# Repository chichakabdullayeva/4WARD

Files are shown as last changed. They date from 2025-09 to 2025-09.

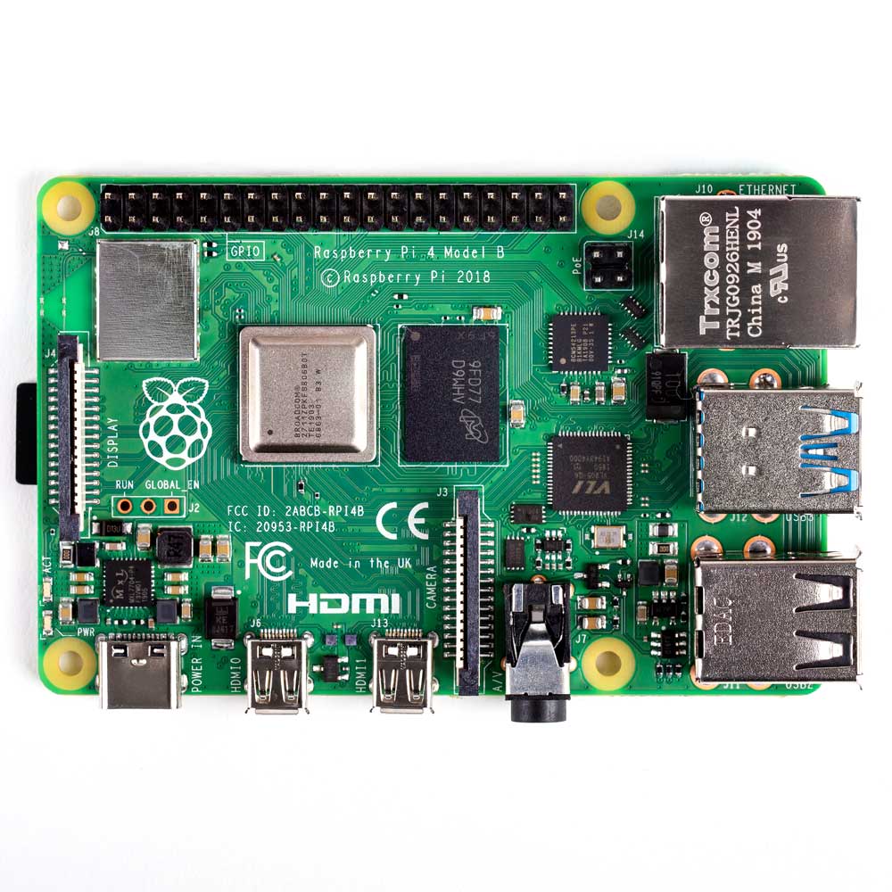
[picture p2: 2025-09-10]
components_picture/Raspberry PI Model 4B.jpg

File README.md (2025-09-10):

# 4Ward

# Engineering Materials for WRO Future Engineers 2025

This repository contains the engineering documentation for **self-driving vehicle of 4ward**, designed for the **World Robot Olympiad (WRO) Future Engineers 2025** competition.  
Our project showcases a fully autonomous vehicle capable of navigating challenges through innovative **mobility, power management, sensing, and obstacle management strategies**.

---

## Team Introduction

**Team 4Ward** consists of three members:  
- **Hakim Musazada**  
- **Shamil Mammadov**  
- **Chichak Abdullayeva**

We are students from **Baku Engineering University**, passionate about electronics, robotics, AI and autonomous systems.  
Our goal is to design a robust vehicle that balances **performance, reliability, and creativity**, inspired by real-world self-driving technology.

Team photos will be uploaded in the [`t-photos/`](./t-photos/) directory:  
- `team-official.jpeg`  → Formal team photo  
- `team-fun.jpeg` → Fun team photo  

---

## Vehicle Design Overview

Our vehicle is designed to excel in the WRO Future Engineers challenges, with a focus on **autonomous navigation, obstacle avoidance, and efficient power usage**.

### Mobility
- Drive system powered by a **single 6V 150 RPM DC motor**
- Rear-wheel drive via **gear system**.  
- **Surpass Hobby 9g D1090FE Digital Servo Motor** controls the front wheels for steering.  
- Motor driver: **TB6612FNG**, interfaced with **Raspberry Pi 4 Model B**.  

This configuration allows **sharp turns, stable movement, and smooth acceleration**.

---

### Power Management
- Powered by **two 3.7V 18650 Li-ion batteries** in series → ~**7.4V / 2200mAh**.  
- **Step-down voltage regulator** provides 5V for Raspberry Pi 4 Model B and sensors.  
- Includes **Battery Management System (BMS)** to prevent over-discharge.  
- Optimized for **20 minutes of continuous operation**.  

Challenge: Voltage drops under heavy motor load → **solved with capacitors** for stable supply.  

---

### Sensing
Our vehicle employs multiple sensors for navigation and obstacle detection:

- **HC-SR04 Ultrasonic Sensors (x3)** → front, left, right (range: 2m).  
- **TCS3200 Color Sensor (x1)** → detect track markers.  
- **Raspberry Pi Camera Module V1.3** → visual recognition & object detection.  

Data is processed in real time on **Raspberry Pi 4 Model B** with noise reduction via **moving average filter**.

---

### Obstacle Management
- Vehicle pauses when obstacle detected.  
- Scans with ultrasonic sensors → calculates alternative path using **rule-based algorithm**.  
- Dynamic obstacles:  
  - **Green cube → pass left**  
  - **Red cube → pass right**  

This ensures **reliable navigation** in the WRO environment.  
Sensor noise was reduced by **averaging multiple readings**.

---

## Electromechanical Schematics
Schematics will be uploaded in the [`schemes/`](./schemes/) directory:  

- `robot_schema_.png` and `robot_schema.jpg` → connections between Raspberry Pi 4 Model B, Camera, HC-SR04, TCS3200, Servo, TB6612FNG, Voltage Regulator, DC Motor and Battery.  

---

## Code Structure and Integration
Source code is located in the [`src/`](./src/) directory, written in **Python** for Raspberry Pi 4 Model B.  

### Code Modules
- `main.py` → Runs the core control loop, combining camera-based color detection, ultrasonic obstacle avoidance, servo steering, and motor control. 
- `camera&servo.py` → Processes camera feed to detect red/green signs and steers the servo using a PD controller.
- `color_sensor.py` → Reads RGB frequencies from TCS3200 sensor, normalizes values, and detects orange or blue objects. 
- `ultrasonic_test`  → Measures distance using HC-SR04 ultrasonic sensor with timeout handling to detect obstacles.
- `ultrasonic&servo&driver.py` → Integrates ultrasonic sensors, camera color detection, motor control, and servo steering for obstacle avoidance and navigation.
### Relation to Hardware
`ultrasonic_test.py` → GPIO 21 (TRIG Front), GPIO 20 (ECHO Front), GPIO 27 (TRIG Left), GPIO 17 (ECHO Left), GPIO 4 (TRIG Right), GPIO 23 (ECHO Right).

`camera_servo.py`' → GPIO 18 (servo pin for camera rotation).

`ultrasonic_servo_driver.py` → GPIO 18 (servo), GPIO 21/20 (front sensor), GPIO 27/17 (left sensor), GPIO 4/23 (right sensor), GPIO 13 (motor PWM), GPIO 24 (MOTOR_IN1), GPIO 25 (MOTOR_IN2).

`color_sensor.py` → Uses OpenCV with camera input (no GPIO pins).

`main.py` → Coordinates modules (no direct GPIO assignment).

## Component Photos
Located in [`components_picture/`](./components-picture/).  

- Raspberry Pi 4 Model B (4GB)  
- Motor (6V, 150 RPM)  
- TB6612FNG Motor Driver  
- HC-SR04 Ultrasonic Sensor  
- Raspberry Pi Camera Module  
- Servo Motor  
- TCS3200 Color Sensor
- LiPo Batteries 18650 

---

## Photos and Videos
- Vehicle Photos → [`v-photos/`](./v-photos/)  
  - `vehicle-front.jpg`, `vehicle-back.jpg`, `vehicle-left.jpg`, `vehicle-right.jpg`, `vehicle-top.jpg`, `vehicle-bottom.jpg`  
- Team Photos → [`t-photos/`](./t-photos/)  
- Demo Videos → [`video/READMDE.md`](./video/video.md) (links to YouTube, ≥30s per challenge)  

---

## Additional Resources
- [`models/`](./models/) → STL files for 3D-printed chassis parts

---

## Contact
For questions, contact us at:  
**team4ward.contact@gmail.com**

---

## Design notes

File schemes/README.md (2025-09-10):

# Note on the Color Sensor – WRO Future Engineers 2025

## Why the Color Sensor Is Missing in the Schematic
The wiring schematic for our vehicle was created using **Fritzing**.  
However, Fritzing does not currently provide a built-in component for the **TCS3200 Color Sensor** (or any similar color sensor).  
Because of this limitation, we were unable to include the color sensor in the uploaded schematic, even though it is an essential part of our actual hardware design.

---

## Purpose of the Color Sensor in Our Vehicle
Although it is missing from the schematic, the **color sensor is fully integrated** in our physical robot and serves a crucial function:

### **Primary Function: Lap Counting**
The main purpose of the color sensor is to **count how many laps the robot has completed** on the track.  
This is critical because:

1. **Race Strategy Requirement**  
   - According to the competition rules, the robot must **complete exactly 3 laps**  
   - After the 3rd lap, the robot must **automatically park** in the designated area

2. **How It Works**  
   - The sensor detects **specific color markers** placed on the track surface  
   - Each time the robot passes over 4 markers, it counts one lap  
   - After detecting the **third marker**, the robot activates its parking system

3. **Precision Timing**  
   - Accurate lap counting ensures the robot stops at the **exact required position**  
   - Without this sensor, the robot would not know when to begin parking procedures

---

## Conclusion
Even though the color sensor is not visible in the schematic due to software limitations, it is a **critical component** for lap counting in our robot.  
It provides the essential capability to:  
- Detect lap completion markers on the track  
- Count exactly 3 laps as required by competition rules  
- Trigger the parking system at the precise moment  

Thus, the **color sensor plays a vital role** in ensuring that our vehicle performs the complete race sequence correctly and stops after exactly 3 laps in the **WRO Future Engineers 2025** competition.

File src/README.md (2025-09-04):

# Source Code Instructions

## Run
python3 main.py

## Hardware
Servo → GPIO 18
Ultrasonic sensors:
  Front → TRIG=21, ECHO=20
  Left  → TRIG=27, ECHO=17
  Right → TRIG=4,  ECHO=23

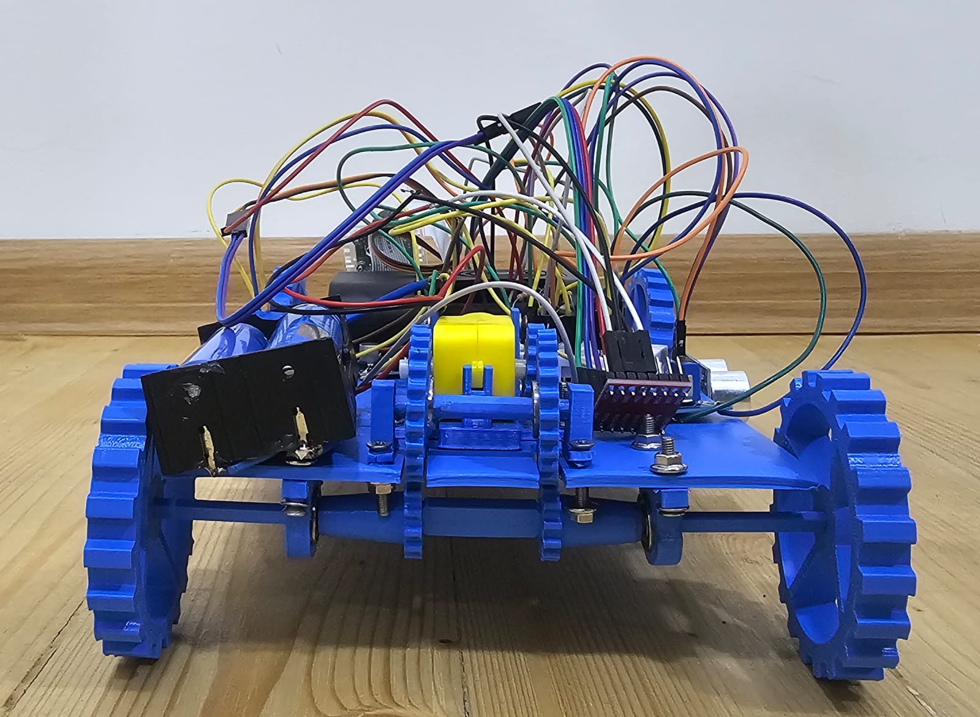
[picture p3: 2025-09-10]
v-photos/vehicle-back.jpg

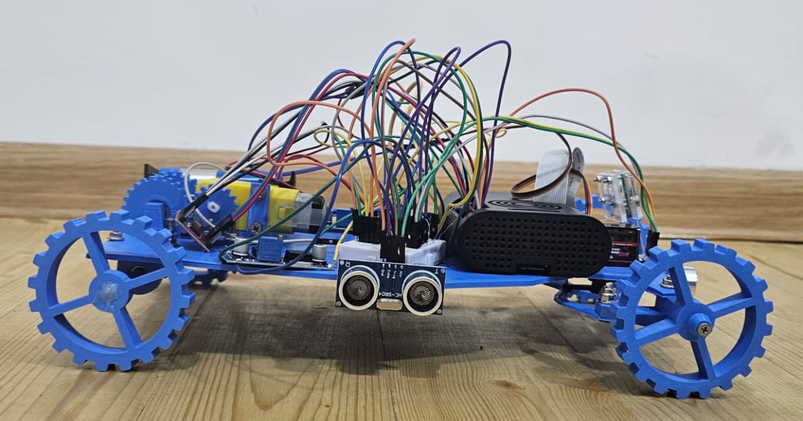
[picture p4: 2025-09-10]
v-photos/vehicle-right.jpg

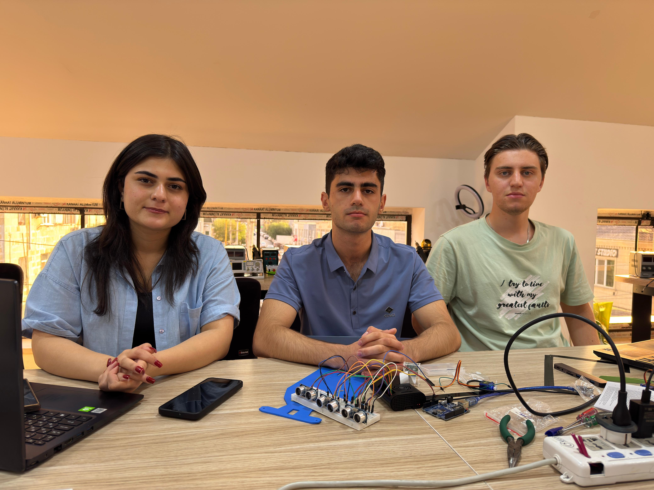
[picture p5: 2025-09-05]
t-photos/team-official.jpeg

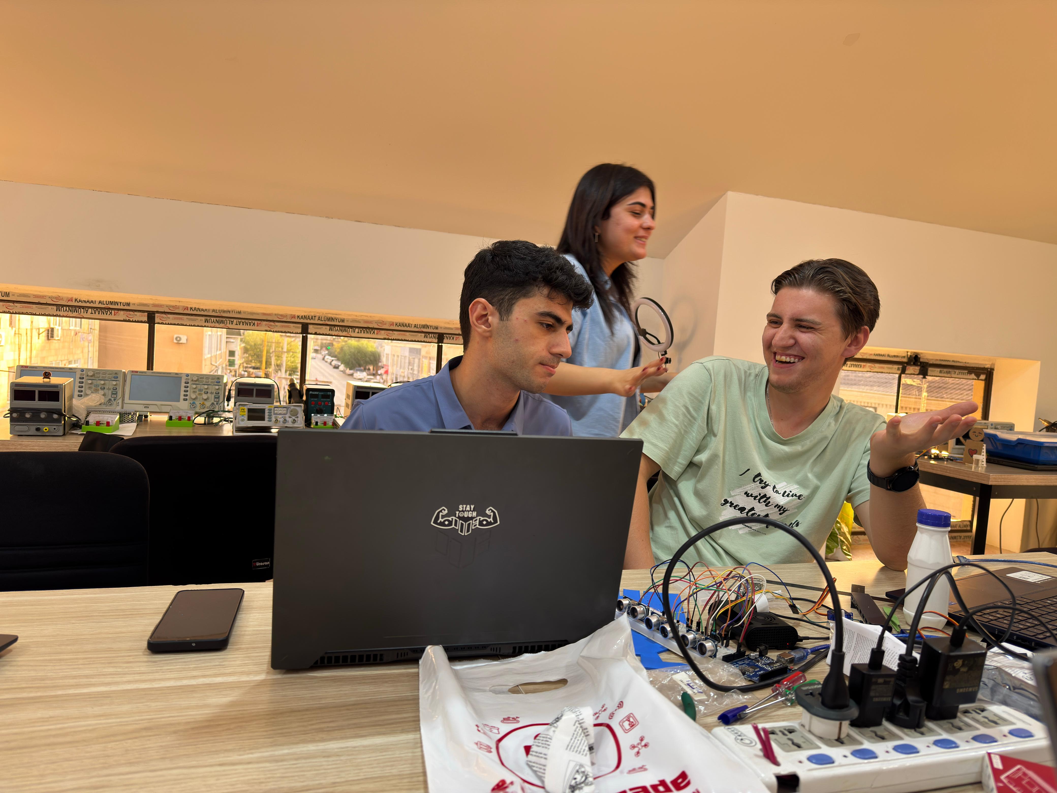
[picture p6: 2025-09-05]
t-photos/team-funny.jpeg

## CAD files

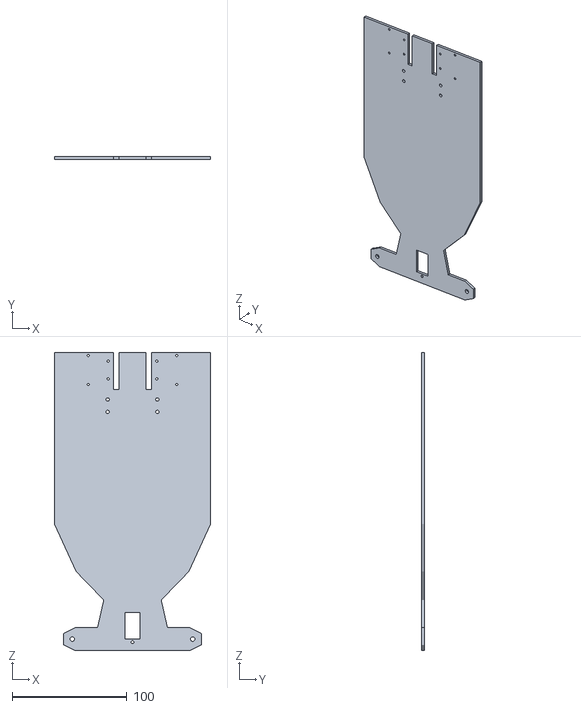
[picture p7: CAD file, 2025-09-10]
models/Part2.STL
136.2 x 2.50 x 260.0

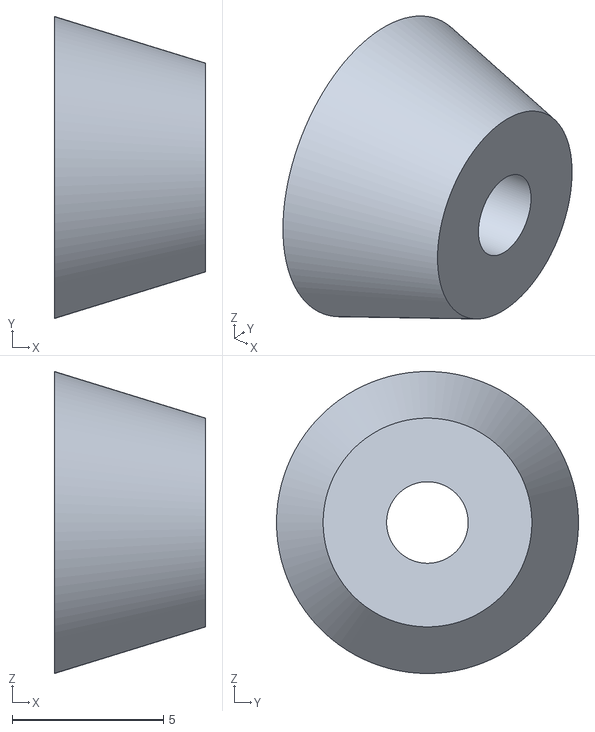
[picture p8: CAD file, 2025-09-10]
models/hubcap_rear.stl
5.00 x 10.0 x 10.0

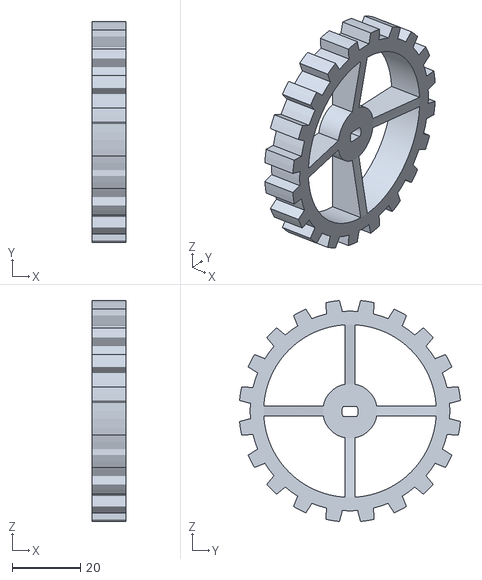
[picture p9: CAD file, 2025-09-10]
models/wheel_rear.stl
10.0 x 65.0 x 65.0

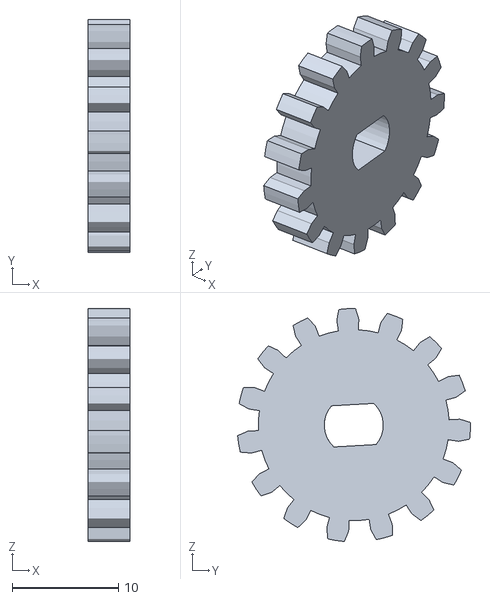
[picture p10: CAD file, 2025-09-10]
models/motor_gear.stl
4.00 x 22.0 x 22.0

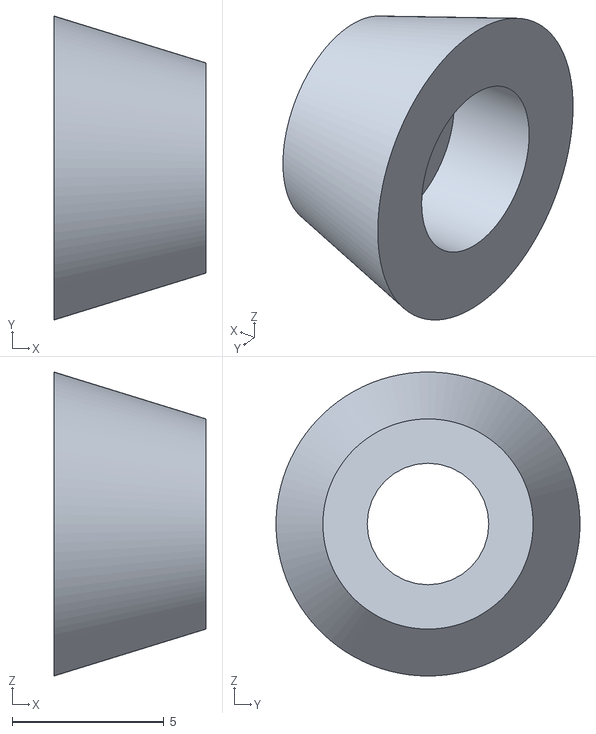
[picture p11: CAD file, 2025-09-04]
models/hubcap_front.stl
5.00 x 10.0 x 10.0

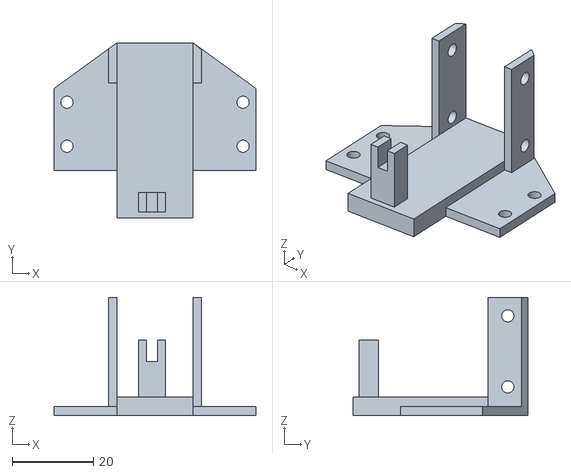
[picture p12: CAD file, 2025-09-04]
models/tt_frame.stl
49.7 x 43.2 x 29.1

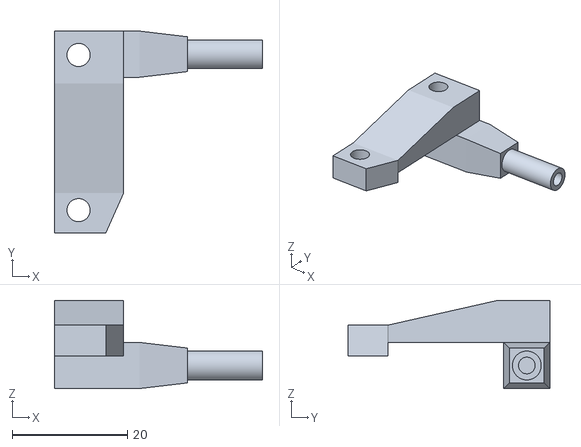
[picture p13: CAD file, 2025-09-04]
models/steering_upright_right.stl
36.0 x 35.0 x 15.3

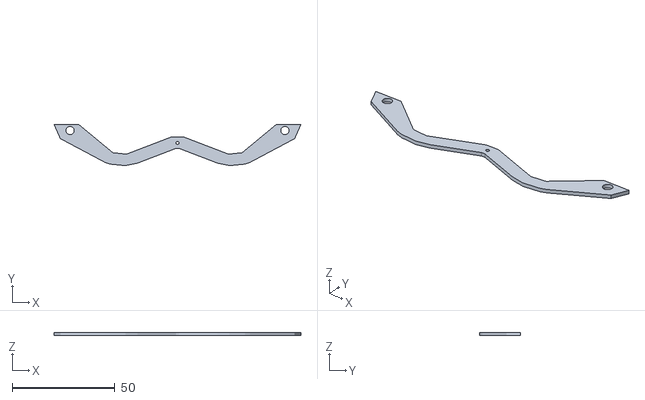
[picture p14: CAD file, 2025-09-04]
models/tie_rod.stl
120.4 x 20.1 x 1.50

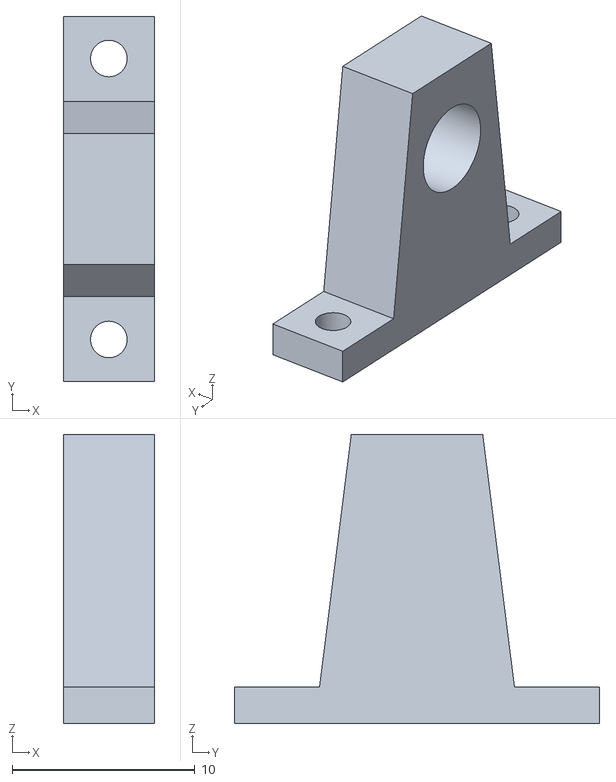
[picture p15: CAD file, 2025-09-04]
models/mid_axle_mount.stl
5.00 x 20.0 x 15.9

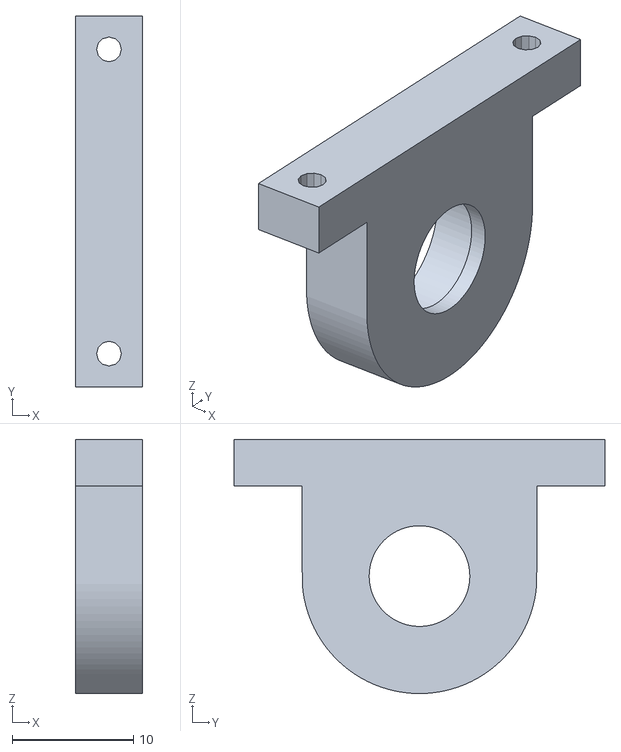
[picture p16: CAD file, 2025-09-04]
models/bearing_mount.stl
5.51 x 30.6 x 21.0

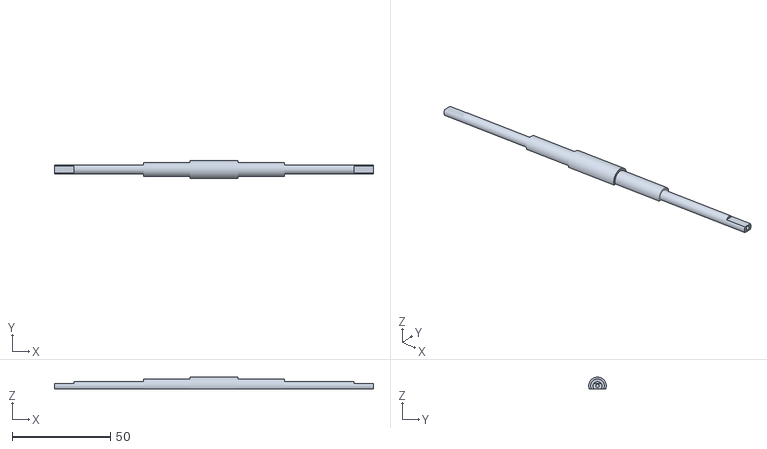
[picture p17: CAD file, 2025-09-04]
models/drive_axle.stl
162.5 x 9.00 x 6.02

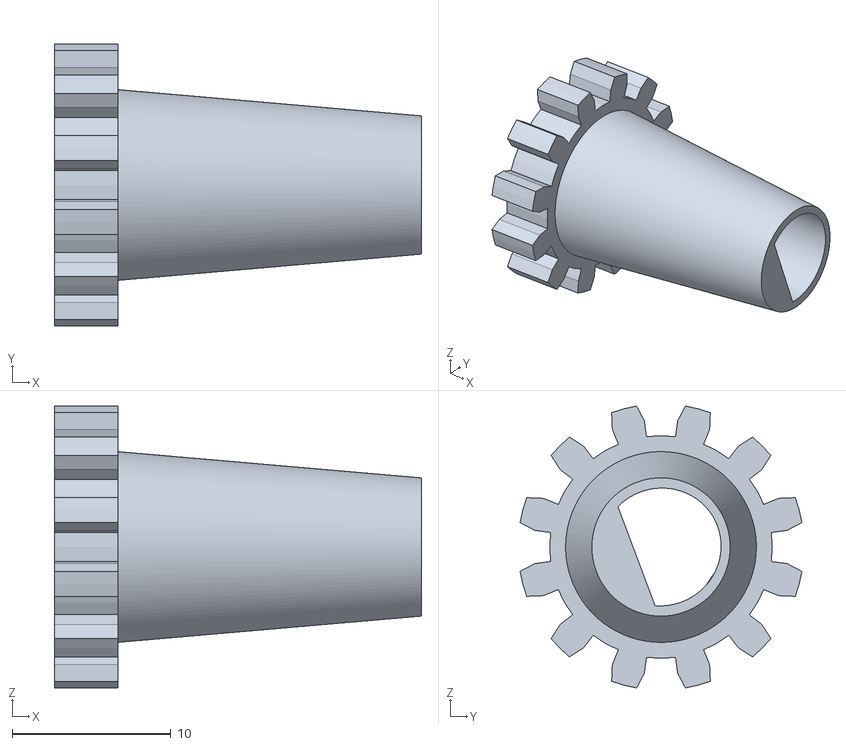
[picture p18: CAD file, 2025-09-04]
models/drive_axle_gear.stl
23.1 x 17.7 x 17.7

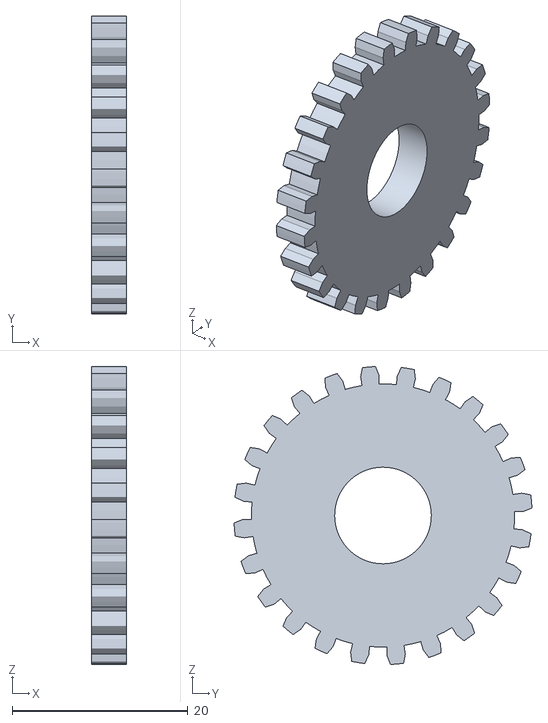
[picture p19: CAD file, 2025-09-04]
models/mid_axle_gear.stl
4.00 x 34.0 x 34.0

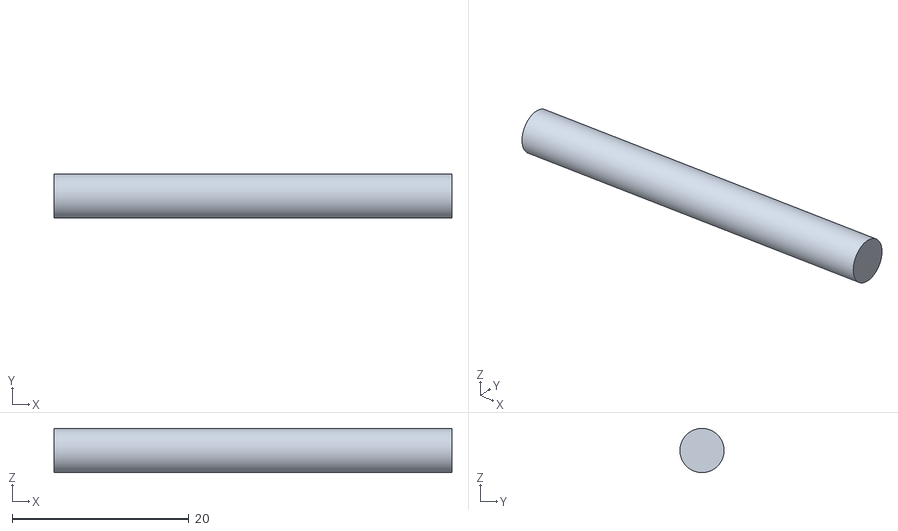
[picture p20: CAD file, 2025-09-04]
models/mid_axle.stl
45.0 x 5.00 x 5.00

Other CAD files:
models/wheel_front.stl
models/steering_upright_left.stl
models/base.stl

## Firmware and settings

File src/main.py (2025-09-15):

import RPi.GPIO as GPIO
import time
import cv2
import numpy as np
import subprocess

SERVO_PIN = 18
FRONT_TRIG = 4
FRONT_ECHO = 23
LEFT_TRIG = 21
LEFT_ECHO = 20
RIGHT_TRIG = 27
RIGHT_ECHO = 17

MOTOR_PWM = 13
MOTOR_IN1 = 24
MOTOR_IN2 = 25

S0_PIN = 22
S1_PIN = 10
S2_PIN = 9
S3_PIN = 11
OUT_PIN = 8

RED_CALIBRATION = 145
GREEN_CALIBRATION = 200
BLUE_CALIBRATION = 200

FILTER_SAMPLES = 5
left_history = [0] * FILTER_SAMPLES
right_history = [0] * FILTER_SAMPLES

GPIO.setwarnings(False)
GPIO.setmode(GPIO.BCM)

GPIO.setup(SERVO_PIN, GPIO.OUT)
pwm_servo = GPIO.PWM(SERVO_PIN, 50)
pwm_servo.start(0)

GPIO.setup(MOTOR_IN1, GPIO.OUT)
GPIO.setup(MOTOR_IN2, GPIO.OUT)
GPIO.setup(MOTOR_PWM, GPIO.OUT)
pwm_motor = GPIO.PWM(MOTOR_PWM, 100)
pwm_motor.start(0)

GPIO.setup(S0_PIN, GPIO.OUT)
GPIO.setup(S1_PIN, GPIO.OUT)
GPIO.setup(S2_PIN, GPIO.OUT)
GPIO.setup(S3_PIN, GPIO.OUT)
GPIO.setup(OUT_PIN, GPIO.IN, pull_up_down=GPIO.PUD_UP)

def setup_ultrasonic_sensor(trig_pin, echo_pin):
    GPIO.setup(trig_pin, GPIO.OUT)
    GPIO.setup(echo_pin, GPIO.IN)
    GPIO.output(trig_pin, False)
    time.sleep(0.2)

setup_ultrasonic_sensor(FRONT_TRIG, FRONT_ECHO)
setup_ultrasonic_sensor(LEFT_TRIG, LEFT_ECHO)
setup_ultrasonic_sensor(RIGHT_TRIG, RIGHT_ECHO)

def get_distance(trig_pin, echo_pin, samples=5):
    values = []
    for _ in range(samples):
        GPIO.output(trig_pin, True)
        time.sleep(0.00001)
        GPIO.output(trig_pin, False)
        
        pulse_start = time.time()
        pulse_end = time.time()
        
        timeout = time.time()
        while GPIO.input(echo_pin) == 0:
            pulse_start = time.time()
            if time.time() - timeout > 0.02:
                return None

        timeout = time.time()
        while GPIO.input(echo_pin) == 1:
            pulse_end = time.time()
            if time.time() - timeout > 0.02:
                return None
        
        pulse_duration = pulse_end - pulse_start
        distance = pulse_duration * 17150
        if distance > 0:
            values.append(distance)
        time.sleep(0.01)

    return round(sum(values) / len(values), 2) if values else None

current_pwm_duty = 8.61
def set_servo_pwm(target_pwm_duty):
    global current_pwm_duty
    
    target_pwm_duty = max(5.89, min(11.33, target_pwm_duty))
    
    step = 0.1 if target_pwm_duty > current_pwm_duty else -0.1
    while abs(current_pwm_duty - target_pwm_duty) > 0.01:
        current_pwm_duty += step
        current_pwm_duty = max(5.89, min(11.33, current_pwm_duty))
        
        pwm_servo.ChangeDutyCycle(current_pwm_duty)
        time.sleep(0.02)
    
    current_pwm_duty = target_pwm_duty
    pwm_servo.ChangeDutyCycle(current_pwm_duty)


def move_forward():
    GPIO.output(MOTOR_IN1, GPIO.HIGH)
    GPIO.output(MOTOR_IN2, GPIO.LOW)
    pwm_motor.ChangeDutyCycle(60)

def stop_motor():
    GPIO.output(MOTOR_IN1, GPIO.LOW)
    GPIO.output(MOTOR_IN2, GPIO.LOW)
    pwm_motor.ChangeDutyCycle(0)

def get_frequency(s2_state, s3_state):
    GPIO.output(S2_PIN, s2_state)
    GPIO.output(S3_PIN, s3_state)
    
    start_time = time.time()
    
    pulse_count = 0
    while time.time() - start_time < 0.1:
        if GPIO.input(OUT_PIN) == 0:
            pulse_count += 1
            while GPIO.input(OUT_PIN) == 0:
                pass
    
    frequency = pulse_count
    return frequency

cmd = ["rpicam-vid", "--width", "320", "--height", "240", "--codec", "mjpeg", "--timeout", "0", "--framerate", "30", "-o", "-"]
proc = subprocess.Popen(cmd, stdout=subprocess.PIPE)
bytes_buffer = b""

frame_width = 320
frame_center = frame_width / 2
MIN_OBJECT_AREA = 2000
FRONT_AVOIDANCE_DISTANCE = 5

consecutive_count = 0
last_detected_color = None
lap_count = 0
last_count_time = 0

try:
    set_servo_pwm(8.61)
    print("System is starting...")
    move_forward()

    while True:
        # Step 1: Check for front obstacles first (highest priority)
        front_dist = get_distance(FRONT_TRIG, FRONT_ECHO)
        if front_dist is not None and front_dist < FRONT_AVOIDANCE_DISTANCE:
            print(f"Front obstacle detected at {front_dist}cm. Stopping.")
            stop_motor()
            set_servo_pwm(8.61)
            time.sleep(0.5)
            continue # Skip to the next loop iteration

        # Step 2: Check for colored objects for avoidance (second priority)
        # Process camera frame
        bytes_buffer += proc.stdout.read(1024)
        a = bytes_buffer.find(b'\xff\xd8')
        b = bytes_buffer.find(b'\xff\xd9')
        if a != -1 and b != -1:
            jpg = bytes_buffer[a:b+2]
            bytes_buffer = bytes_buffer[b+2:]
            frame = cv2.imdecode(np.frombuffer(jpg, dtype=np.uint8), cv2.IMREAD_COLOR)
            hsv = cv2.cvtColor(frame, cv2.COLOR_BGR2HSV)
            
            # Color detection masks
            lower_green = np.array([45, 100, 100])
            upper_green = np.array([65, 255, 255])
            lower_red1 = np.array([170, 120, 120])
            upper_red1 = np.array([179, 255, 255])
            lower_red2 = np.array([0, 120, 120])
            upper_red2 = np.array([10, 255, 255])
            
            mask_green = cv2.inRange(hsv, lower_green, upper_green)
            mask_red1 = cv2.inRange(hsv, lower_red1, upper_red1)
            mask_red2 = cv2.inRange(hsv, lower_red2, upper_red2)
            mask_red = cv2.bitwise_or(mask_red1, mask_red2)
            
            kernel = np.ones((5, 5), np.uint8)
            mask_green = cv2.erode(mask_green, kernel, iterations=1)
            mask_green = cv2.dilate(mask_green, kernel, iterations=1)
            mask_red = cv2.erode(mask_red, kernel, iterations=1)
            mask_red = cv2.dilate(mask_red, kernel, iterations=1)
            
            green_area, red_area = 0, 0
            
            contours_green, _ = cv2.findContours(mask_green, cv2.RETR_EXTERNAL, cv2.CHAIN_APPROX_SIMPLE)
            if contours_green:
                largest_green_contour = max(contours_green, key=cv2.contourArea)
                green_area = cv2.contourArea(largest_green_contour)
            
            contours_red, _ = cv2.findContours(mask_red, cv2.RETR_EXTERNAL, cv2.CHAIN_APPROX_SIMPLE)
            if contours_red:
                largest_red_contour = max(contours_red, key=cv2.contourArea)
                red_area = cv2.contourArea(largest_red_contour)
            
            # Action based on color detection
            if green_area > MIN_OBJECT_AREA:
                print("Green object detected. Turning right.")
                set_servo_pwm(10.83) # Turn right
            elif red_area > MIN_OBJECT_AREA:
                print("Red object detected. Turning left.")
                set_servo_pwm(5.89) # Turn left
            else:
                set_servo_pwm(8.61) # Go straight
                
            cv2.imshow("Camera", frame)
            if cv2.waitKey(1) & 0xFF == ord('q'):
                break
        
        # Step 3: Check for side obstacles if no colored object is in view (third priority)
        left_dist = get_distance(LEFT_TRIG, LEFT_ECHO)
        right_dist = get_distance(RIGHT_TRIG, RIGHT_ECHO)

        if left_dist is not None:
            left_history.append(left_dist)
            left_history.pop(0)
        if right_dist is not None:
            right_history.append(right_dist)
            right_history.pop(0)
        
        avg_left_dist = sum(left_history) / FILTER_SAMPLES
        avg_right_dist = sum(right_history) / FILTER_SAMPLES

        if avg_left_dist < 15 and avg_left_dist > 0:
            set_servo_pwm(10.83) # Turn right
        elif avg_right_dist < 15 and avg_right_dist > 0:
            set_servo_pwm(5.89) # Turn left
        else:
            set_servo_pwm(8.61) # Go straight
        
        # Step 4: Check color sensor for laps (lowest priority)
        current_time = time.time()
        if current_time - last_count_time < 2:
            time.sleep(0.1)
            continue
        
        red_frequency = get_frequency(GPIO.LOW, GPIO.LOW)
        green_frequency = get_frequency(GPIO.HIGH, GPIO.HIGH)
        blue_frequency = get_frequency(GPIO.LOW, GPIO.HIGH)
        
        normalized_red = (red_frequency / RED_CALIBRATION) * 255
        normalized_green = (green_frequency / GREEN_CALIBRATION) * 255
        normalized_blue = (blue_frequency / BLUE_CALIBRATION) * 255
        
        current_color = "UNKNOWN"
        if normalized_blue > normalized_red and normalized_blue > normalized_green and normalized_blue > 150:
            current_color = "BLUE"
        elif normalized_red > normalized_blue and normalized_green > normalized_blue and normalized_red > 150 and normalized_green > 100:
            current_color = "ORANGE"

        if current_color == last_detected_color:
            consecutive_count += 1
        else:
            last_detected_color = current_color
            consecutive_count = 1

        if current_color != "UNKNOWN" and consecutive_count >= 12:
            lap_count += 1
            print(f"Color ({current_color}) detected 12 times in a row! Lap: {lap_count}")
            consecutive_count = 0
            last_detected_color = None
            last_count_time = current_time

        if lap_count >= 3:
            print("Task completed. Laps completed: 3. System is shutting down.")
            break

        time.sleep(0.1)

finally:
    proc.terminate()
    cv2.destroyAllWindows()
    stop_motor()
    pwm_servo.stop()
    pwm_motor.stop()
    GPIO.cleanup()

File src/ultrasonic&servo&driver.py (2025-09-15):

import RPi.GPIO as GPIO
import time

# Ultrasonic sensor pins
FRONT_TRIG = 4
FRONT_ECHO = 23
LEFT_TRIG = 21
LEFT_ECHO = 20
RIGHT_TRIG = 27
RIGHT_ECHO = 17

# Servo pin
SERVO_PIN = 18

# Motor driver pins
MOTOR_IN1 = 24
MOTOR_IN2 = 25
MOTOR_PWM = 13
STBY_PIN = 22

GPIO.setwarnings(False)
GPIO.setmode(GPIO.BCM)

class TB6612MotorDriver:
    def __init__(self, in1_pin, in2_pin, pwm_pin, stby_pin, pwm_freq=1000):
        self.in1_pin = in1_pin
        self.in2_pin = in2_pin
        self.pwm_pin = pwm_pin
        self.stby_pin = stby_pin
        
        # Setup motor GPIO pins
        GPIO.setup([self.in1_pin, self.in2_pin, self.stby_pin], GPIO.OUT)
        GPIO.setup(self.pwm_pin, GPIO.OUT)
        
        # Initialize PWM
        self.pwm = GPIO.PWM(self.pwm_pin, pwm_freq)
        self.pwm.start(0)
        
        # Enable driver (standby off)
        GPIO.output(self.stby_pin, GPIO.HIGH)
        print("Motor driver initialized")
    
    def forward(self, speed):
        speed = max(0, min(100, speed))
        GPIO.output(self.in1_pin, GPIO.HIGH)
        GPIO.output(self.in2_pin, GPIO.LOW)
        self.pwm.ChangeDutyCycle(speed)
        print(f"Motor moving forward at {speed}% speed")
    
    def backward(self, speed):
        speed = max(0, min(100, speed))
        GPIO.output(self.in1_pin, GPIO.LOW)
        GPIO.output(self.in2_pin, GPIO.HIGH)
        self.pwm.ChangeDutyCycle(speed)
        print(f"Motor moving backward at {speed}% speed")
    
    def stop(self):
        GPIO.output(self.in1_pin, GPIO.HIGH)
        GPIO.output(self.in2_pin, GPIO.HIGH)
        self.pwm.ChangeDutyCycle(0)
        print("Motor stopped (brake)")
    
    def coast(self):
        GPIO.output(self.in1_pin, GPIO.LOW)
        GPIO.output(self.in2_pin, GPIO.LOW)
        self.pwm.ChangeDutyCycle(0)
        print("Motor coasting")
    
    def cleanup(self):
        self.pwm.stop()

def setup_ultrasonic_sensor(trig_pin, echo_pin):
    GPIO.setup(trig_pin, GPIO.OUT)
    GPIO.setup(echo_pin, GPIO.IN)
    GPIO.output(trig_pin, False)
    time.sleep(0.2)
    print(f"Sensor on pins TRIG={trig_pin}, ECHO={echo_pin} configured.")

def get_distance(trig_pin, echo_pin, samples=3):
    distances = []
    for _ in range(samples):
        GPIO.output(trig_pin, True)
        time.sleep(0.00001)
        GPIO.output(trig_pin, False)
        
        pulse_start = time.time()
        pulse_end = time.time()
        
        timeout = time.time()
        while GPIO.input(echo_pin) == 0:
            pulse_start = time.time()
            if time.time() - timeout > 0.04:
                return None
        
        timeout = time.time()
        while GPIO.input(echo_pin) == 1:
            pulse_end = time.time()
            if time.time() - timeout > 0.04:
                return None
        
        pulse_duration = pulse_end - pulse_start
        distance_cm = pulse_duration * 17150
        
        if distance_cm > 0:
            distances.append(distance_cm)
            
        time.sleep(0.02)
    
    if distances:
        return round(sum(distances) / len(distances), 2)
    else:
        return None


def set_servo_position(servo_pwm, position):
    """
    Set servo to specific position
    position: 'left', 'center', 'right'
    """
    if position == 'left':
        duty_cycle = 5.5   # 0 degrees (left)
    elif position == 'center':
        duty_cycle = 8.5   # 90 degrees (center)
    elif position == 'right':
        duty_cycle = 12.5  # 180 degrees (right)
    else:
        duty_cycle = 8.5   # default to center
    
    servo_pwm.ChangeDutyCycle(duty_cycle)
    time.sleep(0.3)  # Give servo time to move
    print(f"Servo moved to {position} position (duty cycle: {duty_cycle})")

try:
    # Setup sensors
    setup_ultrasonic_sensor(FRONT_TRIG, FRONT_ECHO)
    setup_ultrasonic_sensor(LEFT_TRIG, LEFT_ECHO)
    setup_ultrasonic_sensor(RIGHT_TRIG, RIGHT_ECHO)
    
    # Setup servo
    GPIO.setup(SERVO_PIN, GPIO.OUT)
    servo_pwm = GPIO.PWM(SERVO_PIN, 50)
    servo_pwm.start(8.5)  # Start at center position
    print("Servo initialized at center position")
    
    # Initialize motor
    motor = TB6612MotorDriver(MOTOR_IN1, MOTOR_IN2, MOTOR_PWM, STBY_PIN)
    
    print("Robot control started... Press Ctrl+C to exit.")
    
    while True:
        left_dist = get_distance(LEFT_TRIG, LEFT_ECHO)
        right_dist = get_distance(RIGHT_TRIG, RIGHT_ECHO)
        front_dist = get_distance(FRONT_TRIG, FRONT_ECHO)
        
        print("-" * 50)
        print(f"Distances - Left: {left_dist}, Right: {right_dist}, Front: {front_dist}")
        
        # Obstacle avoidance logic with motor control
        if front_dist is not None and front_dist <= 10:
            # Obstacle in front - stop and decide direction
            motor.stop()
            set_servo_position(servo_pwm, 'center')
            print("Obstacle ahead! Stopping motor.")
            
            # Check left and right for best path
            if left_dist is not None and right_dist is not None:
                if left_dist > right_dist and left_dist > 10:
                    set_servo_position(servo_pwm, 'left')
                    motor.backward(30)  # Reverse a bit
                    time.sleep(0.5)
                    motor.stop()
                    print("Turning left")
                elif right_dist > 20:
                    set_servo_position(servo_pwm, 'right')
                    motor.backward(30)  # Reverse a bit
                    time.sleep(0.5)
                    motor.stop()
                    print("Turning right")
                else:
                    motor.backward(40)  # Back up if both sides blocked
                    print("Backing up - both sides blocked")
            else:
                motor.backward(40)
                print("Backing up - sensor read error")
                
        elif left_dist is not None and left_dist <= 10:
            # Obstacle on left - turn servo right to avoid it
            set_servo_position(servo_pwm, 'right')
            motor.forward(40)
            print(f"Left obstacle at {left_dist:.2f} cm. Steering right.")
            
        elif right_dist is not None and right_dist <= 10:
            # Obstacle on right - turn servo left to avoid it
            set_servo_position(servo_pwm, 'left')
            motor.forward(40)
            print(f"Right obstacle at {right_dist:.2f} cm. Steering left.")
            
        else:
            # Path clear - move forward with centered servo
            set_servo_position(servo_pwm, 'center')
            motor.forward(50)
            if front_dist is not None:
                print(f"Path clear. Moving forward. Front distance: {front_dist:.2f} cm")
            else:
                print("Path clear. Moving forward. Front sensor error.")
        
        time.sleep(0.3)

except KeyboardInterrupt:
    print("\nProgram terminated by user.")
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

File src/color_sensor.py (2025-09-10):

import RPi.GPIO as GPIO
import time

S2_PIN = 23
S3_PIN = 24
OUT_PIN = 25
LED_PIN = 17


RED_CALIBRATION = 145
GREEN_CALIBRATION = 200
BLUE_CALIBRATION = 200
TOLERANCE = 30

GPIO.setmode(GPIO.BCM)
GPIO.setup(S2_PIN, GPIO.OUT)
GPIO.setup(S3_PIN, GPIO.OUT)
GPIO.setup(OUT_PIN, GPIO.IN, pull_up_down=GPIO.PUD_UP)
GPIO.setup(LED_PIN, GPIO.OUT)

def get_frequency(s2_state, s3_state):
    GPIO.output(S2_PIN, s2_state)
    GPIO.output(S3_PIN, s3_state)
    
    start_time = time.time()
    
    pulse_count = 0
    while time.time() - start_time < 0.1:
        if GPIO.input(OUT_PIN) == 0:
            pulse_count += 1
            while GPIO.input(OUT_PIN) == 0:
                pass
    
    frequency = pulse_count
    return frequency

try:
    print("Color sensor ready. Point at a colored object...")
    GPIO.output(LED_PIN, GPIO.HIGH)

    while True:
        red_frequency = get_frequency(GPIO.LOW, GPIO.LOW)
        green_frequency = get_frequency(GPIO.HIGH, GPIO.HIGH)
        blue_frequency = get_frequency(GPIO.LOW, GPIO.HIGH)

        normalized_red = (red_frequency / RED_CALIBRATION) * 255
        normalized_green = (green_frequency / GREEN_CALIBRATION) * 255
        normalized_blue = (blue_frequency / BLUE_CALIBRATION) * 255
        
        print(f"Raw: R={red_frequency} G={green_frequency} B={blue_frequency}")
        print(f"Normalized: R={normalized_red:.2f} G={normalized_green:.2f} B={normalized_blue:.2f}")

      
        if normalized_blue > normalized_red and normalized_blue > normalized_green and normalized_blue > 150:
            print("Detected Color: BLUE")
        elif normalized_red > normalized_blue and normalized_green > normalized_blue and normalized_red > 150 and normalized_green > 100:
            print("Detected Color: ORANGE")
        else:
            print("Detected Color: UNKNOWN")

        time.sleep(0.2)

except KeyboardInterrupt:
    GPIO.output(LED_PIN, GPIO.LOW)
    GPIO.cleanup()
    print("Program stopped.")
